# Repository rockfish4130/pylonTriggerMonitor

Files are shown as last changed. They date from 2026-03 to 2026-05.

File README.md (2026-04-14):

# Pylons

ESP32-S2 firmware for Lava Lounge fire-effect pylon nodes. Each pylon is a networked device that receives fire-trigger commands via OSC or HTTP, drives solenoids and status LEDs, and reports telemetry back to the RPIBOOSH control system.

## Documentation

| Document | Contents |
|---|---|
| [docs/README.md](docs/README.md) | Full project overview and feature reference |
| [docs/HARDWARE.md](docs/HARDWARE.md) | Board, schematic, GPIO pinout, sensors |
| [docs/SETUP.md](docs/SETUP.md) | Build, flash, serial monitor |
| [docs/WIFI.md](docs/WIFI.md) | Wi-Fi configuration, AP mode, fallback networks |
| [docs/API.md](docs/API.md) | HTTP REST API and OSC reference |
| [docs/CONFIG.md](docs/CONFIG.md) | Node config: NVS, serial CLI, HTTP config API |
| [docs/PYLON_REGISTRY.md](docs/PYLON_REGISTRY.md) | Registry announce/heartbeat payload contract |
| [docs/DISPLAY.md](docs/DISPLAY.md) | OLED page layout and behavior |
| [docs/TROUBLESHOOTING.md](docs/TROUBLESHOOTING.md) | Common problems and fixes |

## Quick Start

```bash
# 1. Create src/wifi_credentials.h  (see docs/WIFI.md)
# 2. Build and flash
pio run -t upload
# 3. Monitor
pio device monitor
```

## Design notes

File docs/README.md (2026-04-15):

# Pylons — Project Overview

## What Is This?

Pylons are autonomous ESP32-S2 nodes deployed at Lava Lounge fire-effect installations. Each pylon:

- Receives fire-trigger commands from the central RPIBOOSH controller via OSC (UDP) or HTTP
- Drives a solenoid output and visual indicator LEDs
- Monitors battery voltage and enclosure temperature
- Reports telemetry (ping, sensors, identity) back to RPIBOOSH
- Can operate standalone via a captive-portal Wi-Fi AP if no venue network is available

The central controller (`RPIBOOSH`, a Raspberry Pi) discovers pylons via the registry API and orchestrates synchronized fire effects across multiple nodes.

---

## Repository Layout

```
pylons/
├── src/
│   ├── main.cpp              # All firmware logic (single file)
│   └── wifi_credentials.h   # NOT committed — local credentials only
├── platformio.ini            # PlatformIO build config
├── schematic_electrical/     # KiCad schematics
│   ├── ESP32_MCU.kicad_sch
│   ├── POWER.kicad_sch
│   └── CONNECTORS.kicad_sch
├── docs/                     # This documentation
└── README.md
```

---

## System Architecture

```
RPIBOOSH (Raspberry Pi)
    │
    ├─ OSC UDP :8000 ──────────► Pylon (ESP32-S2)
    │                                 │
    ├─ HTTP registry API ◄────────────┤  announces + heartbeats
    │                                 │
    └─ HTTP solenoid API ◄────────────┘  web UI / REST
```

Multiple pylons can be on the same network. RPIBOOSH maintains a registry of active nodes via announce/heartbeat and targets individual nodes by ID.

---

## Boot Sequence

1. USB CDC + Serial initialized
2. Task watchdog disabled for `loopTask` (blocking calls are intentional)
3. NVS config loaded (node ID, host, description, AP flag, user WiFi creds)
4. GPIO and ADC pins configured; LEDC PWM channels started for status LEDs
5. I2C + OLED initialized
6. Wi-Fi connection attempted in priority order:
   - `BOOSH_WIFI_SSID_LL` (Lava production, if visible in scan)
   - `BOOSH_WIFI_SSID_MW` (dev/bench network)
   - User-defined fallback SSID (if configured in NVS)
   - If all fail → AP mode auto-enabled and saved to NVS
7. If connected: mDNS, OSC UDP, web server started; pylon announced to registry
8. If AP enabled: SoftAP started on `PYLON_{id}` with captive DNS at `10.1.2.3`

---

## Main Loop

Each iteration (no hard delay except in disconnected/AP-only state):

- `PollBlinkLeds()` — drive status LED square wave (IO12) and sine-wave brightness (IO13/14/15)
- `PollSensors()` — read battery ADC and thermistor every 5 s
- `PollSerialCli()` — process serial CLI input
- `PollDevBoardButton()` — handle dev board button (GPIO0)
- `webServer.handleClient()` — serve HTTP requests
- `dnsServer.processNextRequest()` — captive portal DNS (if AP active)
- Apply live AP enable/disable from config changes
- If Wi-Fi disconnected and not in AP mode: show status and return
- `PollOsc()` — receive and process OSC packets
- `HandleRegistry()` — announce / heartbeat
- Boosh failsafe timeout check
- mDNS host resolution + ping once per second
- OLED page cycle (5 pages, 3 s each)

---

## Features

### Boosh (Fire Trigger)

The primary function. When triggered ON:
- OLED inverts (visual indicator)
- `IO11` goes HIGH (external signal: boosh active)
- `IO12` white LED continues its 1 Hz blink
- Failsafe: if ON is received and OFF is not seen within **5 seconds**, firmware forces OFF

Trigger sources (all equivalent):
- OSC message `/pylon/BooshMain` with float arg `1.0` (ON) or `0.0` (OFF)
- `POST /api/solenoid/on` and `POST /api/solenoid/off`
- Dev-board GPIO0/BOOT button press and release
- Web UI press-and-hold button

### Status LEDs

| Pin | Color | Behavior |
|-----|---|---|
| IO12 | White | 1 Hz square wave — boosh trigger indicator |
| IO13 | Yellow | Sine-wave brightness, ~1.2 Hz, 0–33% |
| IO14 | Blue | Sine-wave brightness, ~0.8 Hz, 0–33% |
| IO15 | Green | Sine-wave brightness, ~0.4 Hz, 0–33% |
| IO11 | — | HIGH when boosh is active |
| IO38 | — | HIGH when Wi-Fi STA connected |

### Battery Sensing (IO3)

Voltage divider: `BATTERY_SENSE_12V → R5(100 kΩ) → R8(22 kΩ) → GND`; junction feeds IO3 via R4(10 kΩ) protection resistor.

- Scale factor: `(100k + 22k) / 22k ≈ 5.545×`
- 100% = 12.7 V (SLA fully charged)
- 0% = 10.5 V (SLA discharged)
- Discharge rate estimated from a rolling 20-minute voltage history (1-min samples). Time-remaining shown in telemetry once 5+ samples are collected.

### Thermistor (IO4)

NTC thermistor in voltage divider with R12 (10 kΩ pull-down), output through R13 (10 kΩ) to IO4.

Steinhart-Hart equation with empirically calibrated coefficients:
- `c1 = 1.274219988e-03`
- `c2 = 2.171368266e-04`
- `c3 = 1.119659695e-07`
- Manual offset: `+11.17 °F` (validated against reference `boosh_box_esp32_remote_thermo` project)

Temperature reported in °F and °C in telemetry.

### Wi-Fi AP Mode

When enabled, pylon broadcasts its own open Wi-Fi network:
- SSID: `PYLON_{id}` (e.g. `PYLON_PYLON5`)
- No password
- Fixed IP: `10.1.2.3`
- DNS server answers all queries with `10.1.2.3` (captive portal)
- OS captive portal detection paths handled: `/generate_204`, `/hotspot-detect.html`, `/ncsi.txt`, `/connecttest.txt`
- Connecting clients are presented with the pylon control page

AP mode is **auto-enabled** if all STA networks fail to connect at boot (and saved to NVS so it persists).

### PYLON Registry

After connecting to Wi-Fi, the pylon announces itself to RPIBOOSH and sends heartbeats every 10 s. See [PYLON_REGISTRY.md](PYLON_REGISTRY.md) for the full payload contract.

---

## See Also

- [HARDWARE.md](HARDWARE.md) — GPIO pinout, schematic notes, ADC circuits
- [SETUP.md](SETUP.md) — build and flash instructions
- [WIFI.md](WIFI.md) — credential file, connection priority, AP mode
- [API.md](API.md) — HTTP REST and OSC reference
- [CONFIG.md](CONFIG.md) — node identity, NVS, CLI, HTTP config
- [PYLON_REGISTRY.md](PYLON_REGISTRY.md) — registry payload contract
- [DISPLAY.md](DISPLAY.md) — OLED page layout
- [TROUBLESHOOTING.md](TROUBLESHOOTING.md)

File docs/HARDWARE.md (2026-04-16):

# Hardware

## Board

**WEMOS / LOLIN S2 Pico** (ESP32-S2)

- MCU: Espressif ESP32-S2FNR2, 240 MHz Xtensa LX7
- Flash: 4 MB embedded
- PSRAM: 2 MB embedded
- USB: Native USB-C (USB CDC, no external UART chip)
- Built-in: SSD1306 128×32 OLED, LiPo charger, user button (GPIO0)
- Official reference: https://www.wemos.cc/en/latest/s2/s2_pico.html

## GPIO Pinout

| GPIO | Direction | Function |
|---|---|---|
| 0 | INPUT_PULLUP | Dev-board BOOT/user button — boosh trigger local test |
| 3 | INPUT (ADC) | Battery voltage sense — R5/R8 voltage divider output |
| 4 | INPUT (ADC) | Thermistor temperature — NTC divider output |
| 8 | I2C SDA | OLED SDA (built-in) |
| 9 | I2C SCL | OLED SCL (built-in) |
| 11 | OUTPUT | HIGH when boosh is active (solenoid-state signal) |
| 12 | OUTPUT | White LED — 1 Hz square wave boosh indicator |
| 13 | OUTPUT (LEDC ch2) | Yellow LED — sine-wave brightness ~1.2 Hz, 0–33% |
| 14 | OUTPUT (LEDC ch1) | Blue LED — sine-wave brightness ~0.8 Hz, 0–33% |
| 15 | OUTPUT (LEDC ch0) | Green LED — sine-wave brightness ~0.4 Hz, 0–33% |
| 18 | OUTPUT | OLED reset (built-in) |
| 38 | OUTPUT | HIGH when Wi-Fi STA connected |

ADC resolution: 12-bit (0–4095), reference 3.3 V.

## Schematic Files

KiCad source in `schematic_electrical/`:

| File | Page |
|---|---|
| `ESP32_MCU.kicad_sch` | ESP32-S2 MCU connections, LED outputs, status IOs |
| `POWER.kicad_sch` | Battery sense, thermistor sense, power rails |
| `CONNECTORS.kicad_sch` | External connector pinout |

## Battery Voltage Sense Circuit

```
BATTERY_SENSE_12V
        │
       R5 (100 kΩ)
        │
        ├──── C2 (100 nF to GND, filter cap)
        │
       R8 (22 kΩ)
        │
       GND

Junction (R5/R8) ──── R4 (10 kΩ) ──── IO3 (ADC)
```

**Theoretical scale factor:** `(100k + 22k) / 22k = 5.545×`

At full-scale ADC (3.3 V on IO3): `3.3 × 5.545 = 18.3 V` measurable max.

**ADC calibration:** Firmware uses `analogReadMilliVolts()` which applies the per-chip eFuse factory calibration baked in at the Espressif factory. No software correction factor is needed. Verified against a bench power supply across the operating range:

| PSU (V) | Reported (V) | Error |
|---|---|---|
| 8.00 | 7.99 | −0.01 V |
| 11.00 | 11.01 | +0.01 V |
| 12.00 | 12.03 | +0.03 V |
| 13.30 | 13.38 | +0.08 V |
| 14.00 | 14.11 | +0.11 V |

Max error <0.8% — within resistor tolerance of the R5/R8 divider. No software trim applied.

Battery % thresholds in `main.cpp` — adjust for battery chemistry:
```cpp
constexpr float kBatteryVoltFull  = 13.6f;   // 100% — LiFePO4 4S fully charged
constexpr float kBatteryVoltEmpty = 11.2f;   // 0%   — LiFePO4 4S discharged
```

## Thermistor Circuit

```
+3.3V ──── THERMO_SENSOR_P ──── [NTC thermistor] ──── THERMO_SENSOR_N
                                                              │
                                                    ├── C3 (100 nF to GND)
                                                    │
                                                   R12 (10 kΩ to GND)
                                                    │
                                                   GND

THERMO_SENSOR_N junction ──── R13 (10 kΩ) ──── IO4 (ADC)
```

Thermistor is the upper element; R12 is the pull-down. ADC reads the divided voltage.

Resistance formula (voltage-direct, using `analogReadMilliVolts()`):
`Rth = R12 × (Vcc_mv − Vadc_mv) / Vadc_mv`

Steinhart-Hart coefficients (empirically calibrated, shared with `boosh_box_esp32_remote_thermo`):
```cpp
c1 = 1.274219988e-03
c2 = 2.171368266e-04
c3 = 1.119659695e-07
```

**2-point linear calibration** applied after Steinhart-Hart, derived on TIKI1 with `analogReadMilliVolts()` ADC:

| Raw S-H (°F) | Reference (°F) |
|---|---|
| 36.63 | 36.00 |
| 74.48 | 73.00 |

`scale = 0.9775`, `offset = +0.20 °F`

```cpp
constexpr float kThermistorCalScale    = 0.9775f;
constexpr float kThermistorCalOffsetF  = 0.20f;
```

## LED Drive Circuit

Each status LED (IO12–15) is driven directly from the ESP32 GPIO through a 1 kΩ current-limiting resistor.

At 3.3 V with 1 kΩ: ~2 mA forward current. Functional but dim. Dropping to 330 Ω gives ~6 mA for better visibility while remaining within the 40 mA GPIO current limit.

## PWM

Status LEDs use the ESP32-S2 LEDC peripheral:

| Channel | Pin | Carrier freq | Signal |
|---|-----|---|---|
| ch0 | IO15 (green) | 5 kHz | Sine envelope 0.4 Hz, 0–33% duty |
| ch1 | IO14 (blue) | 5 kHz | Sine envelope 0.8 Hz, 0–33% duty |
| ch2 | IO13 (yellow) | 5 kHz | Sine envelope 1.2 Hz, 0–33% duty |

IO12 (white) uses `millis()`-based `digitalWrite` for a simple 1 Hz square wave — LEDC at sub-1 Hz carrier was unreliable on this hardware revision.

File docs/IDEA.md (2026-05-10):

# Ideas

Speculative features and directions — not committed to the roadmap.
####

Node config has ID and host fields......
do we really need both? answer carefully.

makes sense to just consolidate into 1 field?

--
add hint text that the field should begin w FIRE-PYLON-

#####

-------------
This should be obvious, but ALWAYS REMEMBER to not "bite the hand that feeds you" meaning watch for conditions and code that could impair an otherwise perfectly usable wifi link.

any questions?

## FAF pattern bug
is there an error in the FAF pattern?

if 2 remotes trigger FAF, I want 2 of the short valve pulses, then 2 of the long open pulses that get longer in time.

I think for N==2, I currenrtly see 3 short pulses and then just one long open pulse.

any questions?
undestand?

## Remote Find-a-Friend Mode

N people each hold an ESP-NOW remote. When multiple people press their buttons at approximately the same time, the pylons recognize the synchronized press and trigger a secret "reward" fire pattern not available through any other means. The more people in sync, the cooler the pattern.
for N remotes pressing the yellow button (roughly) simultaneously: 
if N==2
66 ms valve open
66 ms closed
66 ms valve open
66 ms closed
600 ms valve open
300 ms closed
1200 ms valve open
valve closes, sequence done.

if N==3
66 ms valve open
66 ms closed
66 ms valve open
66 ms closed
66 ms valve open
66 ms closed
600 ms valve open
300 ms closed
1200 ms valve open
300 ms closed
1800 ms valve open
valve closes, sequence done.

etc.

also all a web UI NVS toggle, enabled by default "enable group remote secret pattern" with ample explainer text.

any questions?
how will you handle the "roughly" simult button press timing given human factors and mesh factors?
do we have room for this added code?

## Choreography Protocol

Define a lightweight timing protocol so RPIBOOSH can schedule fire events at specific offsets across multiple pylons without relying on round-trip HTTP latency. Options:

- Relative offset from a shared NTP timestamp
- Sequence packets with pylon-local delay fields
- OSC bundles with timetag

## Sound Trigger Integration

Each pylon could listen for audio amplitude peaks (via an onboard mic or line-in ADC) and self-trigger boosh on beat detection, with RPIBOOSH setting sensitivity and cooldown parameters.

## MQTT Telemetry

Publish sensor readings and boosh events to an MQTT broker for real-time dashboards or integration with home-automation systems at the venue.

## Multi-Solenoid Output

Current hardware drives one solenoid via IO11. A board revision with a relay array or high-side driver could support 2–4 solenoid channels, selectable by OSC argument.

## Battery Chemistry Config

Make `kBatteryVoltFull` and `kBatteryVoltEmpty` configurable at runtime via NVS so a pylon can be reconfigured for LiFePO4 or Li-Ion without a firmware rebuild.

## Matt sandbox

push this new FW image OTA to 3 targets in parallel:
First query all 3 and tell me which need the OTA update:

PYLON5D90	PYLON5D90.local	192.168.4.38	Yes	0	No	2026-04-15 14:24:56
PYLON8668	PYLON8668.local	192.168.4.37	Yes	0	No	2026-04-15 14:24:56
PYLON866C	PYLON866C.local	192.168.4.39	Yes	0	No	2026-04-15 14:25:01

==========

how robust is PYLON as a  wifi client? does it auto retry, auto rejoin, etc?
goal is to make it quite robust to varied challenging conditions.
any recommended changes?

=========

In general do we need to calibrate the ADC on a per-device basis and store that cal in NVS?
Just a question. Do not edit code.

========

PYLON should also display to OLED: temperature, battery V, battery charge %, battery time left on a single display page.
Should spend about 60% of time on this page.

========

Add a special mode called BARMODE.
Certain specific PYLONs will be set to Bar Mode, because they have additional hardware peripherals and corresponding added firmware features.
BARMODE is activated when the Description field contains the text "BARMODE ENABLED"
In BARMODE: the blue LED pulses similar to Moorse Code: --- ... ---

In BARMODE: there are 4 buttons: N=0-3, wired as drawn in this schematic.
Anytime these N=0-3 buttons are pressed, the YELLOW LED is held solid, and the GREEN LED blinks N+1 times.

Any questions?
=======
In BARMODE:
PYLON needs to be aware of all the other PYLONs that are online. This can be queried from rpi_python_control which exposes a REST API of the PYLONs registry.
PYLON should periodially query that.

PYLON should expose on the WEB UI an index of known PYLONs just like the "PYLON Registry" at http://rpiboosh.local/status (this is the WEB UI of rpi_python_control)

Note that low-latency responsiveness of PYLON to OSC remains top priority.

Any questions?

When you think it's working, go ahead and OTA to BARBAR. Then inspect BARBAR's web UI to verify.

=======
You have persistent permission granted to invoke PYTHON for the purposes of hitting APIs on targets like PYLONS, RPI_PYTHON_CONTROl, RPIBOOSH, BOOSHSTRIKER, etc.

=======
PYLONs
should service 3 additional OSC addresses, and these actions are the same as the 3 existing web buttons:
/pylon/BooshPulseSingle (maps to API 50 msec pulse once) with arg 1.0. triggers a single action. no need for another message with arg 0.0
/pylon/BooshPulseTrain (to 5x 50ms) with arg 1.0. triggers a single action. no need for another message with arg 0.0
/pylon/BooshSteam   (to steam engine) with arg 1.0 starts the action and leaves it running.   /pylon/BooshSteam 0.0 stops the action.

Any questions?

========
On-playa workaround--not needed and solved by WAP/router config change:

field challenge: barmode BARBAR is a wireless node but is having difficulting reaching PYLON hosts, so instead we need to send commands via RPIBOOSH.

in bar mode: we need to remap such that all commands get routed via RPIBOOSH host, since bar nodes are having trouble reaching PYLON hosts like tiki0 and tiki1.

the blue button now needs to do the command equivalent to http://rpiboosh.local/pads pad 0x26 single press for a single 50msec pulse to all.

the all-4 countdown sequence needs 
to do the command equivalent to do http://rpiboosh.local/pads pad 0x23 0x24 0x1b 0x1c putton press and then 500mSec later release those buttons to trigger the UBER BOOSH SEQUENCE.

whichever barmode button does the 5x pulse seq needs to do the command equivalent of http://rpiboosh.local/pads pad 0x16 single press and release.

whichever barmode button does the pulse chaser needs to do the command equivalent of http://rpiboosh.local/pads pad 0x1e press and then release.

whichever barmode button does the steam train needs to do the command equivalent of http://rpiboosh.local/pads pad 0xe press and then release.

then tell me the exact path of the FW binary as I will have to manually upload it.

any questions?

=======

Will a PYLON using ESPNOW also be able to be a wifi client? Can it be a wifi AP mode?
Ensure the OLED clearly shows when ESPNOW is active. Print relavent metrics and report details of other PYLONs on the network. Include this in the web status page as well.

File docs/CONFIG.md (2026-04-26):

# Configuration

Node identity and runtime settings are persisted in ESP32 NVS (non-volatile storage) using the `Preferences` library. Changes survive reboots.

## Configurable Fields

| Field | NVS key | Default | Description |
|---|---|---|---|
| Node ID | `id` | `PYLON{MAC}` | Unique node identifier (e.g. `PYLON5`) |
| mDNS host | `host` | same as ID | Hostname for `.local` resolution |
| Description | `desc` | `""` | Human-readable label |
| AP mode | `ap_en` | `false` | Enable Wi-Fi access point |
| User SSID | `usr_ssid` | `""` | 3rd-priority Wi-Fi fallback SSID |
| User password | `usr_pass` | `""` | Password for user fallback SSID |
| Solenoid failsafe | `failsafe_ms` | `5000` | Max solenoid-ON duration before forced OFF (ms) |
| Pylon index | `pylon_idx` | `0` | Sequential fire order; negative = skip |
| No thermistor | `no_thermistor` | `false` | Suppress temperature readings |
| No battery mon | `no_batt_mon` | `false` | Suppress battery readings |
| Use DHCP | `use_dhcp` | `true` | `false` = use static IP config |
| Static IP | `static_ip` | `""` | Static IPv4 address |
| Static gateway | `static_gw` | `""` | Default gateway |
| Static DNS 1 | `static_dns1` | `""` | Primary DNS |
| Static DNS 2 | `static_dns2` | `""` | Secondary DNS |

### BARMODE fields *(only active when description contains `BARMODE ENABLED`)*

| Field | NVS key | Default | Description |
|---|---|---|---|
| Route via RPI | `route_via_rpi` | `false` | Route all pylon OSC commands via rpiboosh HTTP proxy |
| Seq max hold | `seq_max_ms` | `30000` | Blue double-tap+hold: max sequence duration (ms) |
| Seq start delay | `seq_start_ms` | `200` | Blue seq: initial inter-group delay (ms) |
| Seq step decrement | `seq_dec_ms` | `50` | Blue seq: delay reduction per step (ms) |
| Seq floor delay | `seq_floor_ms` | `50` | Blue seq: minimum inter-group delay floor (ms) |
| Seq exp factor | `seq_exp_pct` | `100` | Blue seq: multiplicative factor per step (1–100; 100=linear only) |
| Green timeout | `grn_to_ms` | `300` | Green tap: timed pulse duration (ms) |
| Green recovery | `grn_rec_ms` | `0` | Green tap: cooldown after fire (ms) |
| Blue recovery | `blu_rec_ms` | `0` | Blue tap: cooldown after fire (ms) |
| Orange recovery | `org_rec_ms` | `0` | Orange tap: cooldown after fire (ms) |
| Red recovery | `red_rec_ms` | `0` | Red tap/steam: cooldown after fire (ms) |
| All-4 valve open | `all4_vlv_ms` | `3000` | All-4 sequence: valve hold duration (ms) |
| All-4 lockout | `all4_lck_s` | `300` | All-4 sequence: cooldown before re-trigger (s) |
| Red seq max | `red_seq_max_ms` | `10000` | Red hold sequence: max total duration (ms) |
| Red seq valve | `red_seq_vlv_ms` | `66` | Red hold sequence: valve-open duration per step (ms) |
| Red seq step | `red_seq_stp_ms` | `200` | Red hold sequence: step interval (ms) |

The default node ID is generated from the last two bytes of the MAC address on first boot. Once set explicitly it persists.

---

## Serial CLI

Connect via `pio device monitor` (115200 baud) or any serial terminal.

Commands:

```
help                       — print command list
show                       — print current config values
set id <value>             — set node ID
set host <value>           — set mDNS hostname
set desc <value>           — set node description
set node <value>           — set both id and host to the same value
set ap true|false          — enable or disable Wi-Fi AP mode
set wifi_ssid <value>      — set user fallback Wi-Fi SSID
set wifi_pass <value>      — set user fallback Wi-Fi password
clear nvs                  — erase all saved config (resets to defaults on next boot)
```

All `set` commands save to NVS immediately. AP mode change takes effect at the next main loop iteration (no reboot required).

---

## HTTP Config API

See [API.md](API.md) for full endpoint reference.

Quick reference:

```bash
# Read current config
curl http://<pylon-ip>/api/config

# Set node identity
curl -X POST http://<pylon-ip>/api/config/node -d "value=PYLON5"

# Set description
curl -X POST http://<pylon-ip>/api/config/desc -d "value=Center striker"

# Enable AP mode
curl -X POST http://<pylon-ip>/api/config/ap -d "value=true"

# Set user WiFi fallback
curl -X POST http://<pylon-ip>/api/config -d "wifi_ssid=MyNetwork&wifi_pass=MyPassword"
```

---

## Web UI

The web UI at `http://<pylon-ip>/` exposes the same config fields via a form panel. Changes are sent via the REST API and take effect immediately.

---

## Compile-Time Constants

These are set in `src/main.cpp` and require a rebuild to change:

| Constant | Default | Description |
|---|---|---|
| `kPylonIdDefaultPrefix` | `"PYLON"` | Prefix for auto-generated node ID |
| `kRegistryBaseUrlPrimary` | `"http://rpiboosh.local:5000"` | RPIBOOSH registry URL (mDNS) |
| `kRegistryBaseUrlFallback` | `""` | Fixed-IP fallback registry URL |
| `kRegistryTtlSec` | `30` | Registry TTL in seconds |
| `kRegistryHeartbeatIntervalMs` | `10000` | Heartbeat interval |
| `kRegistryHttpTimeoutMs` | `2500` | HTTP timeout for registry posts |
| `kOscPort` | `8000` | UDP OSC port |
| `kBooshFailsafeTimeoutMs` | `5000` | Max boosh ON duration before forced OFF |
| `kFirmwareVersion` | `"0.0.1 DATE TIME"` | Build identity string |

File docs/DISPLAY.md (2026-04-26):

# Display

## Hardware

- Controller: SSD1306
- Resolution: 128×32
- I2C address: `0x3C`
- SDA: GPIO8, SCL: GPIO9, Reset: GPIO18

## Initialization

```cpp
Wire.begin(8, 9);
display.begin(SSD1306_SWITCHCAPVCC, 0x3C);
```

Reset pin is set to GPIO18 before `begin()`.

## Boot Messages

During setup the OLED shows progress messages: OLED ready, Wi-Fi scan, connecting, IP address on success, or failure.

## Runtime Pages

Pages cycle every ~3 seconds (`kDisplayCycleMs`). The pylon rotates through up to 6 pages (slot 6 only shown in BARMODE):

### Page 1 — Ping

```
RPIBOOSH
OK  last:7ms
min:2 max:17
since: 00:05:23
```

- Status: `OK`, `FAIL`, or `TIMEOUT` (no successful ping within `kPingTimeoutMs`)
- Shows last/min/max RTT and elapsed time since last successful ping

### Page 2 — Wi-Fi A

```
SSID: MyNetwork
RSSI: -58 dBm
IP: 192.168.1.70
UP: 02:32:03
```

### Page 3 — Wi-Fi B

```
RSN: 0 (none)
SSID: MyNetwork
RSSI: -58
IP: 192.168.1.70
```

`RSN` shows the last Wi-Fi disconnect reason code and a short label.

### Page 4 — Node

```
PYLON5
Triggers: 12
v0.0.1
```

### Page 5 — Firmware

```
v0.0.1
Apr 13 2026
12:00:00
```

### Page 6 — Pylon Ping *(BARMODE only)*

```
PYLON PING
avg 5ms N=8 ok
!TIKI3 timeout
```

- Line 1: `PYLON PING` header
- Line 2: overall average RTT across all known pylons, node count, and `ok` or `Nx!` (N timeouts)
- Lines 3–4: names of any pylons with a timeout on their last ping attempt
- Populated by the per-pylon ping loop in `PingTask` (Core 0); one pylon pinged per second in rotation

## Boosh Indicator

When boosh is active (solenoid ON), the entire display inverts (white-on-black → black-on-white). This is the primary visual confirmation of a fire trigger.

Trigger sources that cause inversion: OSC, HTTP API, web UI, dev-board button.

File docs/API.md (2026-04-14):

# API Reference

## OSC

**Transport:** UDP  
**Port:** 8000  
**Address:** `/pylon/BooshMain`

| Argument | Type | Meaning |
|---|---|---|
| `1.0` | float | Boosh ON |
| `0.0` | float | Boosh OFF |

The message must have exactly one float argument. Any other shape is ignored.

**Example** (raw hex, ON):
```
2F 70 79 6C 6F 6E 2F 42 6F 6F 73 68 4D 61 69 6E 00 00 2C 66 00 00 00 00 3F 80 00 00
```

**Example** (raw hex, OFF):
```
2F 70 79 6C 6F 6E 2F 42 6F 6F 73 68 4D 61 69 6E 00 00 2C 66 00 00 00 00 00 00 00 00
```

---

## HTTP REST

All endpoints are on port 80. Responses are JSON unless noted.

### `GET /`

Returns the web UI (HTML).

---

### `GET /api/telemetry`

Returns full device telemetry.

**Response fields:**

| Field | Type | Description |
|---|---|---|
| `pylon_id` | string | Node identifier |
| `description` | string | Human-readable node description |
| `hostname` | string | mDNS hostname (`.local`) |
| `ip` | string | Current IPv4 address |
| `fw_version` | string | Firmware build string |
| `fw_semver` | string | Semantic version (e.g. `0.0.1`) |
| `fw_build_date` | string | Compile date |
| `fw_build_time` | string | Compile time |
| `uptime` | string | Uptime as `HH:MM:SS` |
| `uptime_hms` | string | Alias for `uptime` |
| `solenoid_active` | bool | `true` when boosh is firing |
| `trigger_event_count` | int | Total boosh trigger count since boot |
| `ap_enabled` | bool | AP mode enabled in config |
| `ap_active` | bool | AP currently running |
| `target_ip` | string | Resolved IP of RPIBOOSH |
| `battery_voltage_v` | float\|null | Battery voltage in volts |
| `battery_charge_pct` | float\|null | Battery charge 0–100% |
| `battery_time_remaining_h` | float\|null | Estimated hours remaining (null until 5+ samples) |
| `temperature_f` | float\|null | Enclosure temperature in °F |
| `telemetry` | object | Nested telemetry for registry compatibility (see [PYLON_REGISTRY.md](PYLON_REGISTRY.md)) |

---

### `GET /api/logs`

Returns recent serial log output as seen in the web UI console.

**Response:**
```json
{ "log": "...\n...\n" }
```

---

### `GET /api/config`

Returns current node configuration.

**Response fields:**

| Field | Type | Description |
|---|---|---|
| `id` | string | Node ID (e.g. `PYLON5`) |
| `host` | string | mDNS host (e.g. `PYLON5`) |
| `hostname` | string | Full hostname (e.g. `PYLON5.local`) |
| `description` | string | Node description |
| `ap_enabled` | bool | AP mode enabled |
| `ap_active` | bool | AP currently active |
| `wifi_ssid` | string | User-defined fallback SSID (empty if not set) |

---

### `POST /api/config`

Updates one or more config fields. Accepts `application/x-www-form-urlencoded` or JSON form args.

**Form args (all optional):**

| Arg | Description |
|-----|---|
| `node` | Sets both `id` and `host` to the same value |
| `id` | Node ID |
| `host` | mDNS host |
| `description` or `desc` | Node description |
| `wifi_ssid` | User fallback SSID |
| `wifi_pass` | User fallback password |
| `ap_enabled` | `true`/`false`/`1`/`0` |

Changes are persisted to NVS immediately.

---

### `POST /api/config/id`

Sets node ID from form arg `value`.

### `POST /api/config/host`

Sets mDNS host from form arg `value`.

### `POST /api/config/desc`

Sets description from form arg `value`.

### `POST /api/config/node`

Sets both ID and host from form arg `value`.

### `POST /api/config/ap`

Enables or disables AP mode. Form arg `value`: `true`/`false`.

---

### `POST /api/solenoid/on`

Activates boosh (solenoid ON). Equivalent to OSC `1.0`. The 5-second failsafe applies.

**Response:**
```json
{ "ok": true, "solenoid_active": true, "triggered_via": "http" }
```

### `POST /api/solenoid/off`

Deactivates boosh (solenoid OFF).

**Response:**
```json
{ "ok": true, "solenoid_active": false, "triggered_via": "http" }
```

### `POST /api/solenoid/trigger`

Alias for `/api/solenoid/on`.

---

## Boosh Failsafe

If boosh is activated (via any method) and OFF is not received within **5 seconds**, firmware forces it OFF automatically. Serial log: `Failsafe: BooshMain timeout -> forcing OFF.`

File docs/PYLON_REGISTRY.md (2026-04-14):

# PYLON Registry Integration

The pylon announces itself to RPIBOOSH on Wi-Fi connect and sends periodic heartbeats. RPIBOOSH uses these to build and maintain a live registry of active nodes.

## Endpoints

Base URL: `http://rpiboosh.local:5000` (compile-time `kRegistryBaseUrlPrimary`)  
Optional fixed-IP fallback: `kRegistryBaseUrlFallback` in `src/main.cpp`

| Method | Path | When |
|---|---|---|
| `POST` | `/api/pylons/announce` | On Wi-Fi connect or reconnect |
| `POST` | `/api/pylons/heartbeat` | Every 10 seconds after announce |

## Runtime Behavior

1. On Wi-Fi connect, firmware posts an `announce`.
2. After a successful announce, posts `heartbeat` every `kRegistryHeartbeatIntervalMs` (10 s).
3. If ping to RPIBOOSH fails and later recovers, a fresh `announce` is posted.
4. On post failure, retries with exponential backoff capped to 30 s.
5. HTTP timeout: `kRegistryHttpTimeoutMs` (2.5 s) to avoid blocking the main loop.

Serial log prefixes: `[REG] announce`, `[REG] heartbeat`, `[REG] post failed`.

## Payload

Both `announce` and `heartbeat` send the same JSON body:

```json
{
  "pylon_id": "PYLON5",
  "description": "Center striker",
  "hostname": "PYLON5.local",
  "ip": "192.168.1.70",
  "osc_port": 8000,
  "osc_paths": ["/pylon/BooshMain"],
  "roles": ["boosh_main"],
  "fw_version": "0.0.1 Apr 13 2026 12:00:00",
  "firmware_version": "0.0.1 Apr 13 2026 12:00:00",
  "version": "0.0.1 Apr 13 2026 12:00:00",
  "ttl_sec": 30,
  "telemetry": {
    "ipv4": "192.168.1.70",
    "mdns_hostname": "PYLON5.local",
    "fw_version": "0.0.1 Apr 13 2026 12:00:00",
    "fw_semver": "0.0.1",
    "fw_build_date": "Apr 13 2026",
    "fw_build_time": "12:00:00",
    "temperature": 72.5,
    "temperature_f": 72.5,
    "temperature_c": 22.5,
    "battery_voltage": 12.4,
    "battery_voltage_v": 12.4,
    "battery_charge": 86.4,
    "battery_charge_pct": 86.4,
    "battery_time_remaining_h": 4.2,
    "wifi_rssi_dbm": -58,
    "uptime_s": 9123,
    "uptime": "02:32:03",
    "uptime_hms": "02:32:03",
    "ping_target": "RPIBOOSH",
    "ping": {
      "target": "RPIBOOSH",
      "sent": 151,
      "recv": 143,
      "lost": 8,
      "last_ms": 7,
      "min_ms": 2,
      "max_ms": 17,
      "avg_ms": 6,
      "count": 143,
      "last_ok": true,
      "since_ok_s": 1,
      "since_ok": "00:00:01"
    }
  }
}
```

Sensor fields (`temperature`, `battery_voltage`, `battery_charge`, `battery_time_remaining_h`) are `null` JSON when the sensor has not yet returned a valid reading (e.g. shortly after boot, or if the ADC returns an out-of-range value).

## Field Contract

Receivers must ignore unknown fields. Field meanings are stable — do not rename or repurpose existing fields.

| Field | Type | Notes |
|---|---|---|
| `pylon_id` | string | Stable node identifier |
| `description` | string | Human-readable label |
| `hostname` | string | mDNS hostname ending in `.local` |
| `ip` | string | Current IPv4 |
| `osc_port` | int | UDP OSC port (8000) |
| `osc_paths` | string[] | Accepted OSC addresses |
| `roles` | string[] | Node capability roles |
| `fw_version` | string | Full build string |
| `ttl_sec` | int | Registry TTL |
| `telemetry.temperature` | float\|null | Temperature in °F |
| `telemetry.temperature_f` | float\|null | Temperature in °F |
| `telemetry.temperature_c` | float\|null | Temperature in °C |
| `telemetry.battery_voltage` | float\|null | Battery voltage (V) |
| `telemetry.battery_voltage_v` | float\|null | Alias |
| `telemetry.battery_charge` | float\|null | Battery charge (%) |
| `telemetry.battery_charge_pct` | float\|null | Alias |
| `telemetry.battery_time_remaining_h` | float\|null | Hours remaining (null until 5+ history samples) |
| `telemetry.wifi_rssi_dbm` | int | Wi-Fi RSSI |
| `telemetry.uptime_s` | int | Uptime in seconds |
| `telemetry.ping_target` | string | Ping target hostname |
| `telemetry.ping.sent` | int | Total ping attempts since boot |
| `telemetry.ping.recv` | int | Successful ping replies |
| `telemetry.ping.lost` | int | Failed attempts |
| `telemetry.ping.last_ms` | int | Last RTT in ms |
| `telemetry.ping.min_ms` | int | Min RTT in ms |
| `telemetry.ping.max_ms` | int | Max RTT in ms |
| `telemetry.ping.avg_ms` | int | Average RTT in ms |
| `telemetry.ping.last_ok` | bool | `true` if most recent ping succeeded |

## Forward Compatibility

- Add fields; do not rename or repurpose existing ones.
- New fields should be optional from the receiver's perspective.
- Nest new measurements under `telemetry` so older consumers ignore them cleanly.
- For non-additive evolution, add an explicit `schema` or `protocol` marker rather than silently changing baseline fields.

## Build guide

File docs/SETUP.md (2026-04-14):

# Setup

## Prerequisites

- [PlatformIO](https://platformio.org/) (VS Code extension or CLI)
- USB-C data cable (not charge-only)
- WEMOS/LOLIN S2 Pico board

## Credential File

Before building, create `src/wifi_credentials.h`. This file is gitignored and must be created locally. See [WIFI.md](WIFI.md) for the template and explanation.

## Build

```bash
pio run
```

## Upload

```bash
pio run -t upload
```

Upload port is set to `COM16` in `platformio.ini`. Change this to match your system.

If the upload fails, the board may need to be manually put into bootloader mode:

1. Hold the `0`/BOOT button
2. Tap `RST`
3. Release `0`
4. Run the upload command

After flashing, tap `RST` once to reboot into firmware. The USB CDC port re-enumerates on reboot — if the port disappears, wait a few seconds and try again.

## Serial Monitor

```bash
pio device monitor
```

Baud rate: `115200` (set in `platformio.ini`).

USB CDC is used (no external UART chip). Requires `ARDUINO_USB_CDC_ON_BOOT=1` and `ARDUINO_USB_MODE=0` build flags, which are already set in `platformio.ini`.

## Dependencies

Declared in `platformio.ini`. PlatformIO installs automatically:

| Library | Purpose |
|---|---|
| `Adafruit GFX Library` | OLED graphics primitives |
| `Adafruit SSD1306` | OLED driver |
| `ESP32Ping` | ICMP ping to RPIBOOSH |
| `CNMAT/OSC` | OSC packet parsing |
| `DNSServer` | Captive portal DNS (bundled with ESP32 Arduino core) |

## Dev-Board Button

On the WEMOS S2 Pico, the `0`/BOOT button doubles as a local boosh trigger:

- Press → boosh ON
- Release → boosh OFF

This is equivalent to sending an OSC `/pylon/BooshMain` message.

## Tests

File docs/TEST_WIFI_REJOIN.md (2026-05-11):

# WiFi Rejoin Test — Procedure, Results, and Capabilities

## Purpose

Verify that PYLONs running the WiFi-probe firmware correctly rejoin the WAP (LavaLounge) after
a WAP outage, even when auto-AP mode was activated at boot.

---

## Background / What Is Being Tested

Prior to commit `838d8cd`, a PYLON that booted while the WAP was unavailable would:
1. Enable auto-AP (`ap_auto_enabled = true`) on `cfg_mesh_ch` (ch 11)
2. Never rejoin WiFi — the active AP pins the radio to ch 11, so `WiFi.reconnect()` cannot
   scan other channels, and the 10-min auto-reboot is suppressed by `ap_active`

The fix (`838d8cd`) adds a **probe sequence**:
- When a non-barmode PYLON has been offline long enough to trigger a reconnect attempt and
  `ap_auto_enabled` is true, it temporarily stops the AP, calls `WiFi.begin()`, and waits up to
  15 s for a connection
- On success: `ap_auto_enabled` is cleared; node stays on WiFi
- On timeout: AP is restored on `cfg_mesh_ch`; node remains mesh-only until next attempt

---

## Test Performed — 2026-05-10

### Firmware Under Test

| Commit | Description |
|---|---|
| `838d8cd` | WiFi probe introduced (core fix) |
| `63514f4` | Mesh panel hw/cfg channel display |
| `8120680` | Barmode probe guard (BARBAR AP preservation) |

All nodes were OTA'd to `8120680` before/after the test. The test run itself used `838d8cd`
(barmode guard not yet present — BARBAR AP regression found during this test, see below).

### Nodes Participating

| Node | Action during test | WiFi at test start |
|---|---|---|
| FIRE-PYLON-BARBAR | Reset while WAP down | LavaLounge |
| FIRE-PYLON-REDTEST | Reset while WAP down | LavaLounge |
| FIRE-PYLON-YELLOWTEST | Reset while WAP down | LavaLounge |
| FIRE-PYLON-TIKI0 | Reset while WAP down | LavaLounge |
| FIRE-PYLON-TIKI1 | Not reset (old firmware, excluded) | LavaLounge |

### Procedure

1. All probe-capable nodes confirmed online and on LavaLounge via registry
2. WAP (LavaLounge) powered off
3. BARBAR, REDTEST, YELLOWTEST, TIKI0 manually reset (power cycle) while WAP was down
   — nodes boot, fail WiFi, enter auto-AP + mesh-only mode
4. WAP powered back on (~2 min startup)
5. Claude monitored registry via background polling (2-min interval) and node logs via curl

### Results

- All 4 rebooted nodes showed the probe sequence in `/api/logs` at **~583 s offline**
  (matches the 10-min reconnect interval minus mesh-peer-live suppression offset)
- All 4 connected to LavaLounge successfully; `ap_auto_enabled` cleared
- `ap=false` in registry heartbeat confirmed auto-AP correctly disabled post-rejoin

**PASS** for the core probe mechanism.

### Bug Found During Test

BARBAR's always-on AP was disabled by the probe code and never restored after rejoining WiFi.
Root cause: `ap_auto_enabled = true` is set unconditionally at boot on WiFi failure — the same
flag the probe checks — even for barmode nodes whose AP is user-requested, not auto.

Fix: added `&& !barmode_active` guard to probe condition (`8120680`).

---

## Test Performed — 2026-05-10 (Round 2) — Barmode AP Preservation

### Firmware Under Test

| Commit | Description |
|---|---|
| `8120680` | Barmode probe guard |
| `2aa7ee6` | Reconnect watchdog: `WIFI_AP_STA`+`WiFi.begin()` for AP-active nodes; `!barmode_active` guard in GOT_IP handler |

### What Was Tested

BARBAR-specific path: boot with WAP down → auto-AP starts → reconnect watchdog fires repeatedly
→ WAP comes back → `GOT_IP — auto_ap=1 active=1` → AP must survive.

Two bugs were discovered and fixed iteratively during this session:

**Bug 1** (`8120680` → `2aa7ee6`): Reconnect watchdog called `WiFi.reconnect()` for barmode nodes.
`SetupApMode()` sets `WIFI_AP` (not `WIFI_AP_STA`) when STA is disconnected, disabling the STA
interface entirely. `WiFi.reconnect()` is a no-op with no STA. Fix: switch to `WIFI_AP_STA` +
`WiFi.begin()` when `ap_active`.

**Bug 2** (`2aa7ee6`): `ARDUINO_EVENT_WIFI_STA_GOT_IP` handler cleared `ap_enabled` when
`ap_auto_enabled && ap_active` — correct for regular nodes, wrong for barmode. Fix: added
`!barmode_active` guard.

### Results

```
[WiFi] Offline 463s — reconnect attempt (peers=4 ap=1).
[WiFi] GOT_IP — auto_ap=1 active=1
WiFi connected: mDNS/OSC/web restarted (ap_active=1 ap_auto=1)
```

`ap_active=1` confirmed after rejoin with `auto_ap=1` at GOT_IP — the exact previously-failing
path. BARBAR reachable on LavaLounge at uptime 8:08 with `ap=true`.

**PASS** — Gap #1 fully closed.

---

## Test Capabilities — What Claude Can Do

During a structured hardware/firmware test, Claude can perform the following without prompting:

| Capability | How |
|---|---|
| Poll registry for node presence / heartbeat fields | `curl http://rpiboosh.local:5000/api/nodes` |
| Poll individual node telemetry | `curl http://<ip>/api/telemetry` |
| Fetch node console log | `curl http://<ip>/api/logs` |
| Scan subnet for live nodes | curl sweep of 192.168.4.1–60 on port 80 |
| Background polling loop | Bash background task writing timestamped output |
| Build firmware | `/c/Users/Matt/.platformio/penv/Scripts/pio.exe run -e lolin_s2_pico` |
| OTA firmware to any/all nodes in parallel | `curl -X POST http://<ip>/api/ota -F firmware=@...` |
| Reconnect this PC to LavaLounge WiFi | `netsh wlan connect name=LavaLounge` |
| Reboot a node via API | `curl -X POST http://<ip>/api/reboot` |
| Push NVS config to a node | `curl -X POST http://<ip>/api/config -d ...` |
| Commit and push after test | `git add / commit / push` |
| Evaluate pass/fail from log patterns | grep probe/connect strings in `/api/logs` output |

Claude **cannot**:
- Power hardware on or off
- Press physical reset buttons
- Observe LEDs or OLED display
- Know exact timing of physical events without being told

---

## Manual Steps — What the User Provides

| Step | Notes |
|---|---|
| Power WAP on / off | Tell Claude immediately when done — timing matters |
| Reset / power-cycle individual nodes | Specify which nodes and approximately when |
| Confirm WAP startup complete | WAP typically takes ~2 min to be joinable |
| Observe OLED / LED state | Describe or photograph if relevant to the test |
| Report unexpected physical observations | e.g. a node's LED not responding, OLED frozen |

**Timing protocol:** Tell Claude the moment each manual action occurs (WAP off, node reset, WAP
on). Claude logs receipt time as a proxy for event time and uses it to interpret probe intervals
in node logs.

---

## Re-running This Test

Recommended sequence:

1. Confirm all nodes online and on LavaLounge: Claude polls registry
2. Claude starts background polling task (2-min interval)
3. Power WAP off → tell Claude
4. Reset target nodes (not BARBAR unless specifically testing barmode) → tell Claude which ones
5. Wait ~5 min (probe fires at the reconnect interval, ~10 min from last live-peer contact)
6. Power WAP on → tell Claude
7. Claude polls logs on each node to confirm probe sequence and rejoin
8. Claude reports pass/fail per node

For a faster iteration (skip the 10-min wait): reduce `cfg_wifi_reconnect_s` to 60 s via web UI
before the test, restore to 600 s after.

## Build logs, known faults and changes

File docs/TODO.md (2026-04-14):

# TODO

## Open

- [ ] Replace hardcoded `osc_paths` legacy string in registry payload with dynamic `kOscAddress` — done in firmware, but verify RPIBOOSH receiver accepts `/pylon/BooshMain` path.
- [ ] Validate Steinhart-Hart thermistor calibration on installed hardware (current coefficients are from `boosh_box_esp32_remote_thermo` reference project).
- [ ] Reduce LED resistors from 1 kΩ to 330 Ω on next board revision for better visibility (current ~2 mA; 330 Ω gives ~6 mA, still within GPIO 40 mA limit).
- [ ] Add OTA firmware update support.
- [ ] Add NTP time sync for timestamped telemetry.
- [ ] Multi-pylon synchronized fire choreography (timing protocol between RPIBOOSH and pylons).

## Done

- [x] OSC boosh trigger (`/pylon/BooshMain`)
- [x] HTTP REST API (solenoid on/off, telemetry, config)
- [x] Web UI with hold-to-fire button, live telemetry, config panel, log console
- [x] Status LEDs: IO12 white 1 Hz, IO13 yellow sine 1.2 Hz, IO14 blue sine 0.8 Hz, IO15 green sine 0.4 Hz
- [x] IO11 = HIGH when boosh active; IO38 = HIGH when Wi-Fi STA connected
- [x] Boosh failsafe (5-second forced OFF)
- [x] RPIBOOSH registry: announce + heartbeat with exponential backoff
- [x] Battery voltage sensing and % on IO3
- [x] Battery time-remaining estimation (rolling 20-min history)
- [x] Thermistor temperature on IO4 (Steinhart-Hart, calibrated)
- [x] Wi-Fi AP mode with captive portal (DNSServer, OS detection paths)
- [x] User-defined Wi-Fi fallback (SSID/password in NVS)
- [x] NVS config persistence (id, host, desc, ap_en, user WiFi)
- [x] Serial CLI for config
- [x] OLED 5-page display cycle
- [x] TWDT watchdog disabled for loopTask (prevents resets from blocking calls)
- [x] Web UI log scroll lock (only auto-scrolls when already at bottom)
- [x] Full documentation suite

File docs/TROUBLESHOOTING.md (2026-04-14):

# Troubleshooting

## Upload Fails / Port Not Found

- Use a data-capable USB-C cable (not charge-only).
- Check that the board appears in your device list.
- On normal boot, the firmware enumerates a USB CDC serial port automatically.
- If auto-reset fails, manually enter bootloader: hold `0`/BOOT, tap `RST`, release `0`, then start upload.
- After flashing, tap `RST` once to reboot. The COM port re-enumerates after a few seconds.
- If PlatformIO serial monitor was open, close it before uploading — it may hold the port.

## OLED Is Blank

- Confirm board is WEMOS/LOLIN S2 Pico (has built-in 128×32 SSD1306).
- I2C address must be `0x3C`.
- Reset pin must be `GPIO18`.
- Check `Wire.begin(8, 9)` is called before `display.begin()`.

## Serial Output Missing

- Confirm baud rate is `115200`.
- Ensure build flags `ARDUINO_USB_CDC_ON_BOOT=1` and `ARDUINO_USB_MODE=0` are set in `platformio.ini`.
- Watch for boot markers: `Boot: OLED ready`, `Boot: WiFi STA mode`, `WiFi scan...`.

## Wi-Fi Does Not Connect

- Verify SSIDs and passwords in `src/wifi_credentials.h`.
- ESP32-S2 supports 2.4 GHz only — 5 GHz networks are invisible.
- Each network attempt has a 15-second timeout before moving to the next.
- If all three networks fail, AP mode is auto-enabled.
- Connection order: Lava (`LL`) → dev (`MW`) → user-defined fallback.

## AP Mode Enabled Unexpectedly

If AP mode was auto-enabled because all STA networks failed, it is saved to NVS and persists on reboot. To disable:

```bash
# Via serial CLI
set ap false

# Via HTTP (when connected)
curl -X POST http://<pylon-ip>/api/config/ap -d "value=false"
```

Or use the web UI toggle.

## Cannot Connect to AP

- SSID is `PYLON_{id}` (e.g. `PYLON_PYLON5`) — open network, no password.
- Fixed IP is `10.1.2.3`.
- If captive portal does not appear, navigate directly to `http://10.1.2.3/`.

## OSC Not Responding

- Confirm UDP port `8000` is open on the network.
- OSC address is `/pylon/BooshMain` (not `/rpiboosh/BooshMain` — that was a legacy path).
- Message must have exactly one float argument: `1.0` (ON) or `0.0` (OFF).
- Test locally: press the `0`/BOOT button on the dev board (ON on press, OFF on release).

## Boosh Turns Off Unexpectedly

The 5-second failsafe forces OFF if no OFF message arrives within 5 s of ON. Serial log: `Failsafe: BooshMain timeout -> forcing OFF.`

This is intentional. Ensure the OFF message is sent promptly after ON.

## Battery / Temperature Reads Null

- Sensor values show `null` for the first poll cycle (~5 seconds after boot).
- If they remain null, check ADC wiring against [HARDWARE.md](HARDWARE.md).
- Battery ADC on IO3 reads 0 or 4095 if the divider is open or shorted — these are rejected.
- Thermistor ADC on IO4 reads 0 or 4095 if the NTC is open or shorted — these are also rejected.

## Battery Time Remaining Shows Null

Time remaining is estimated from a rolling 20-minute voltage history using 1-minute samples. It shows `null` until at least 5 samples are collected (~5 minutes after boot) and the battery is actively discharging.

## Registry Announce / Heartbeat Failing

- Check serial logs for `[REG]` prefixed lines.
- Confirm RPIBOOSH is reachable: `http://rpiboosh.local:5000`.
- If mDNS does not resolve `rpiboosh.local`, set `kRegistryBaseUrlFallback` to a fixed IP URL in `src/main.cpp`.
- Verify the registry service paths: `POST /api/pylons/announce`, `POST /api/pylons/heartbeat`.

## Device Resets After a Few Minutes (Watchdog)

Watchdog resets were caused by blocking HTTP and ping calls stalling the `loopTask` beyond the TWDT threshold. This is fixed in current firmware via `esp_task_wdt_delete(NULL)` in `setup()`, which removes `loopTask` from watchdog monitoring. If you see watchdog resets, confirm `#include "esp_task_wdt.h"` and the `esp_task_wdt_delete(NULL)` call are present in `src/main.cpp`.

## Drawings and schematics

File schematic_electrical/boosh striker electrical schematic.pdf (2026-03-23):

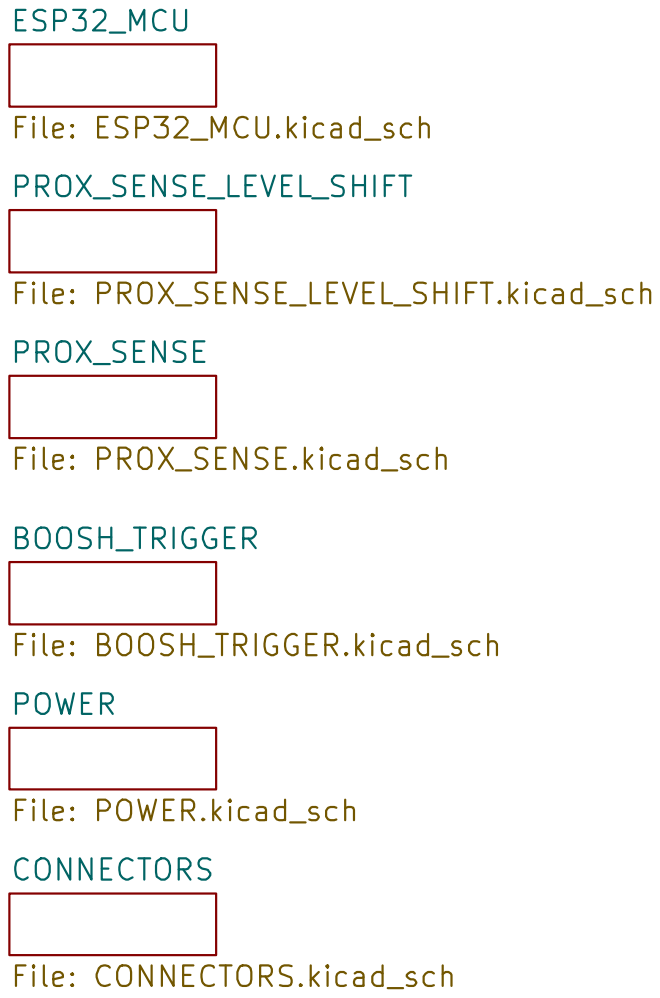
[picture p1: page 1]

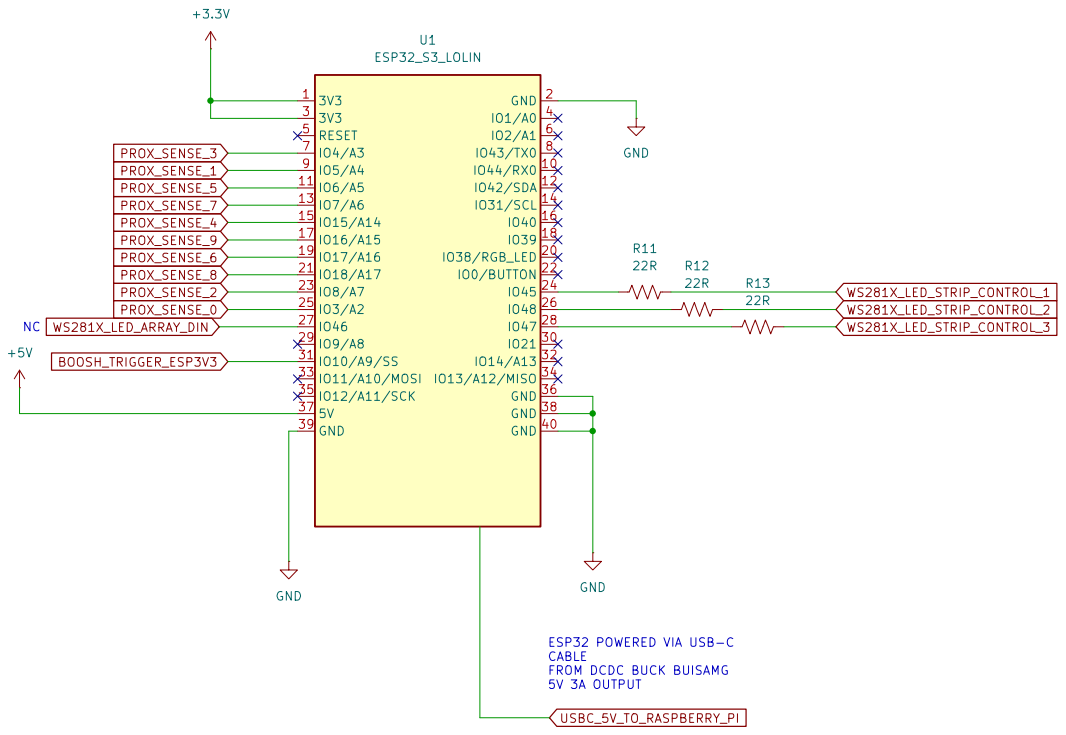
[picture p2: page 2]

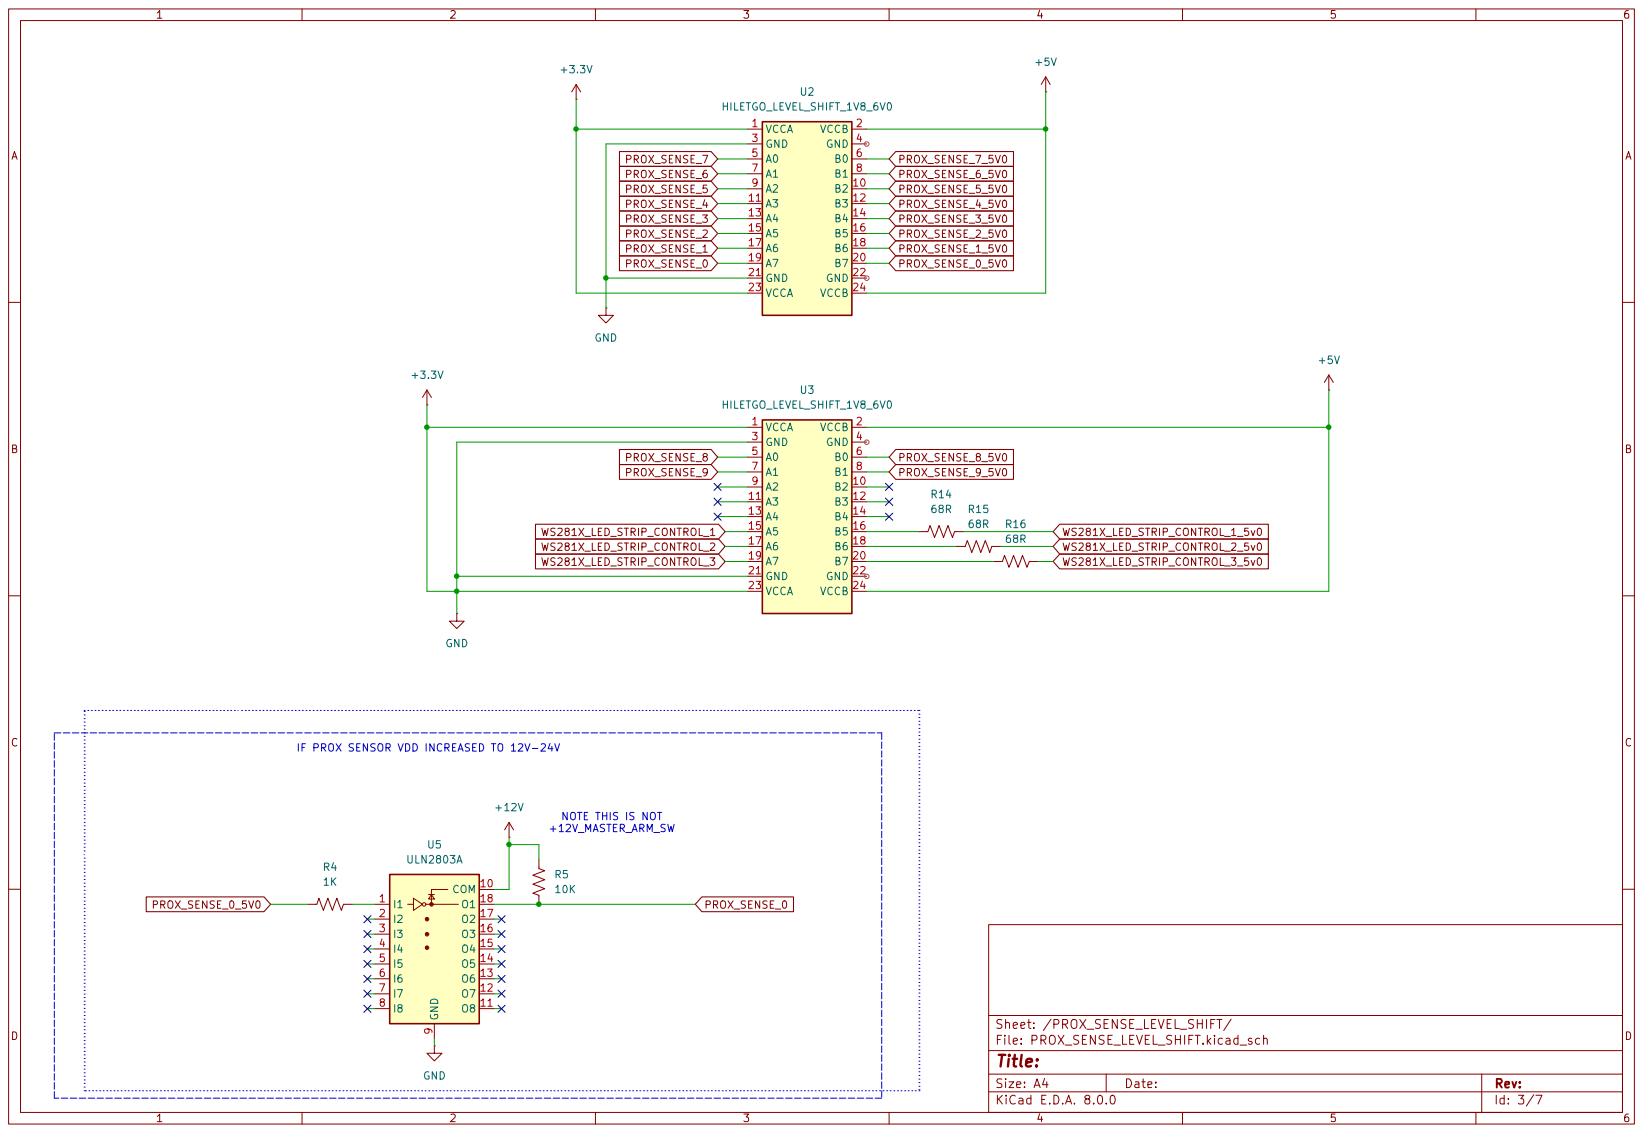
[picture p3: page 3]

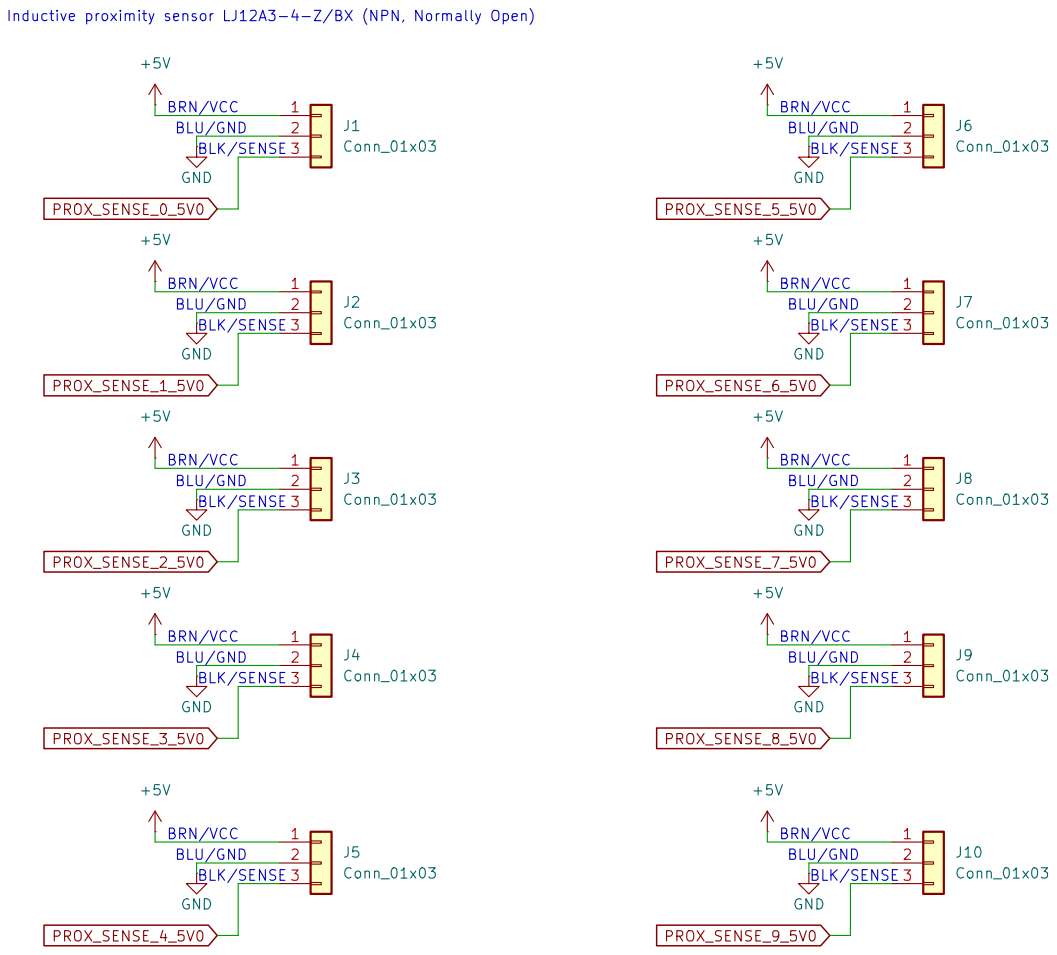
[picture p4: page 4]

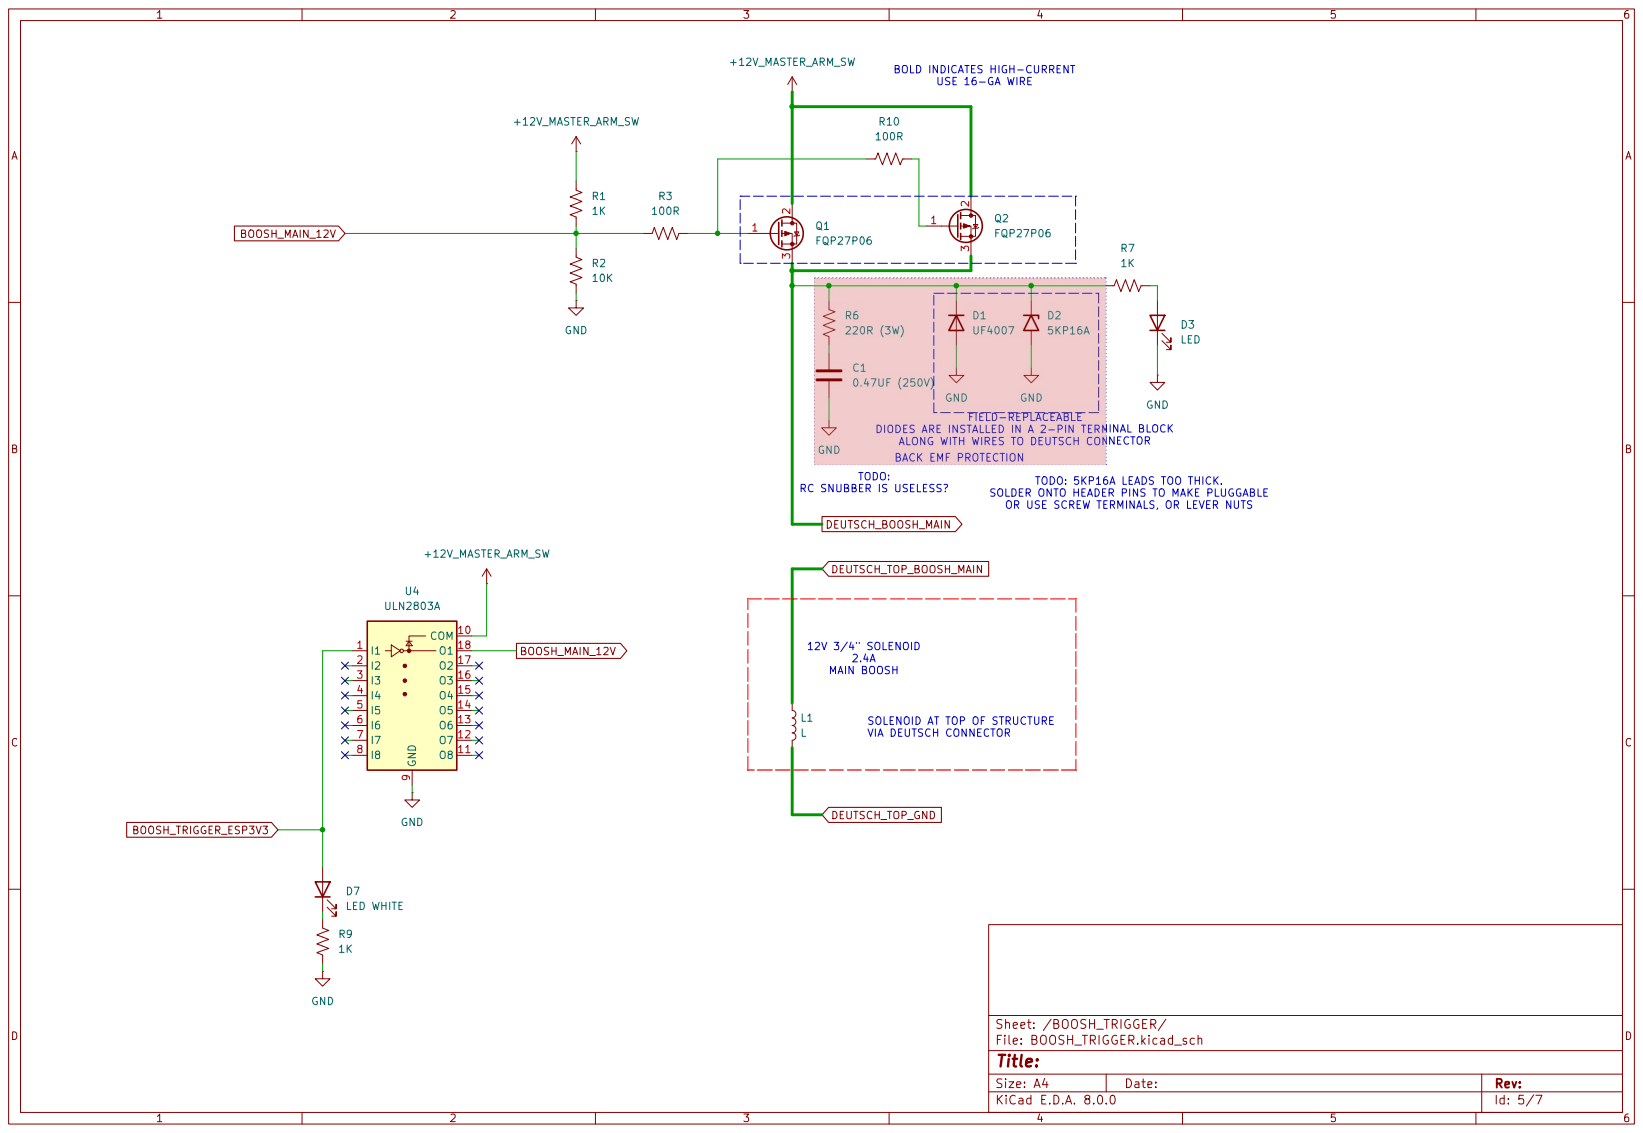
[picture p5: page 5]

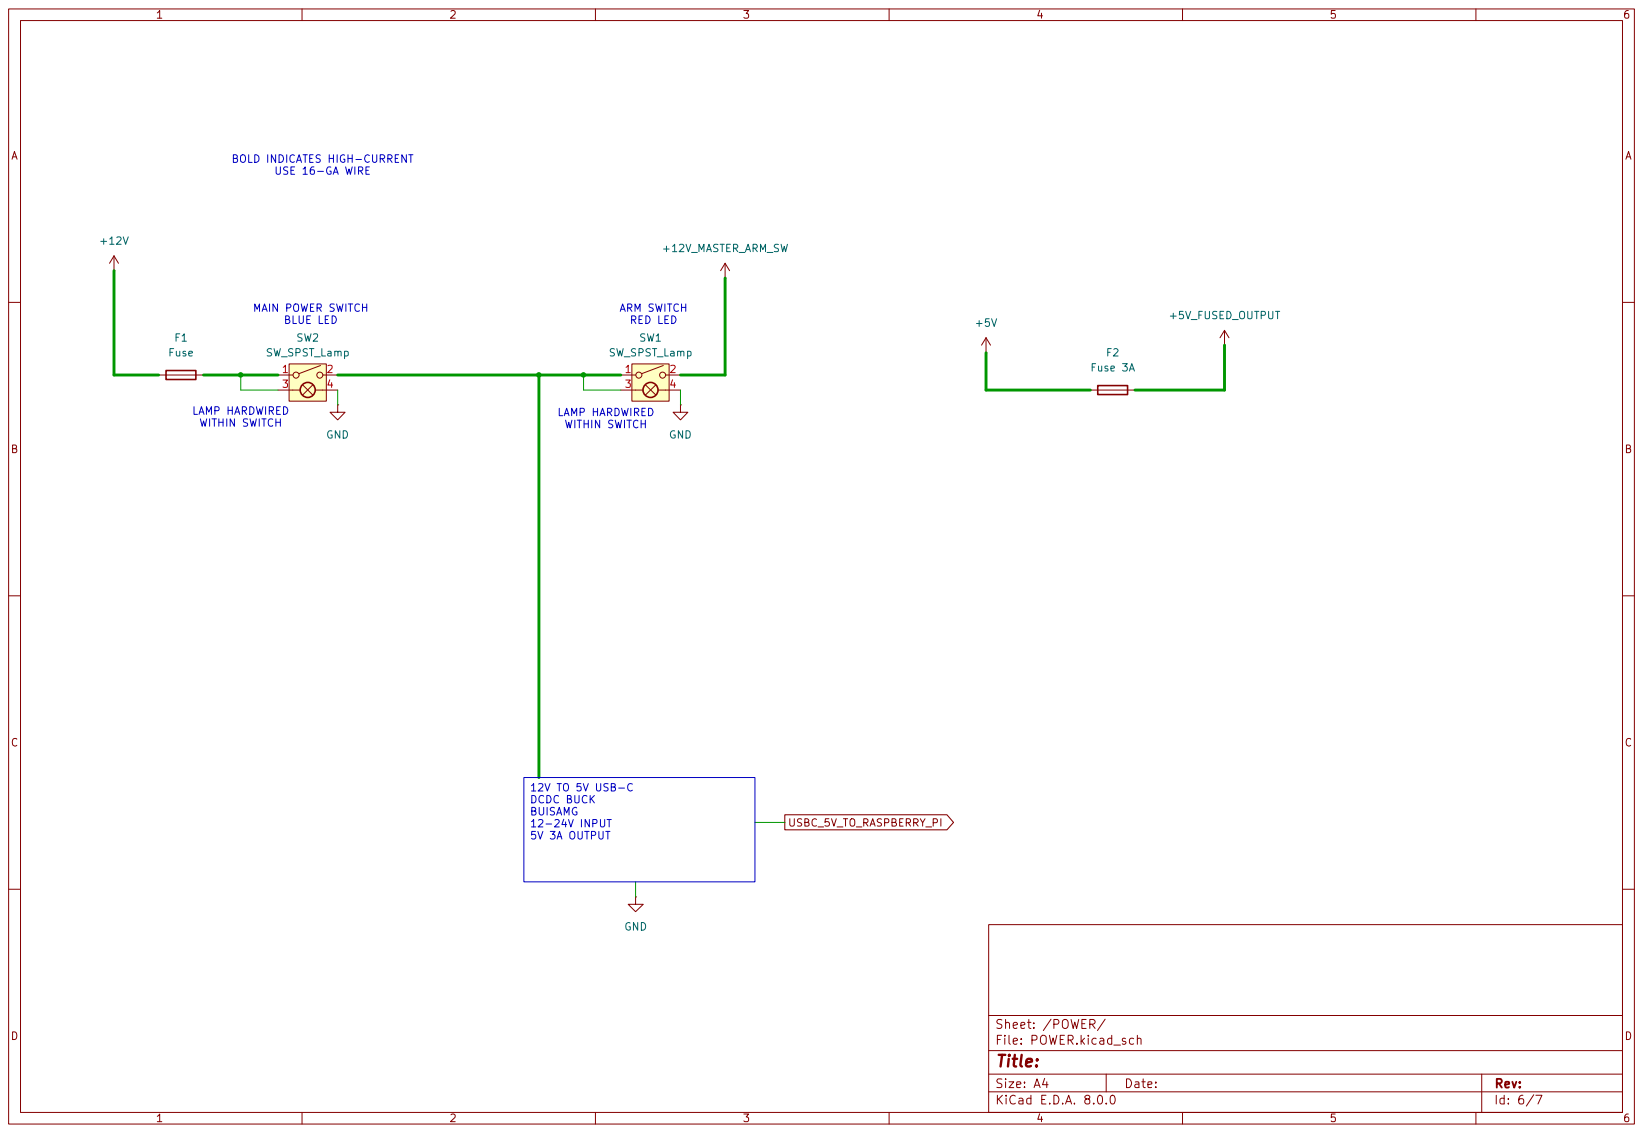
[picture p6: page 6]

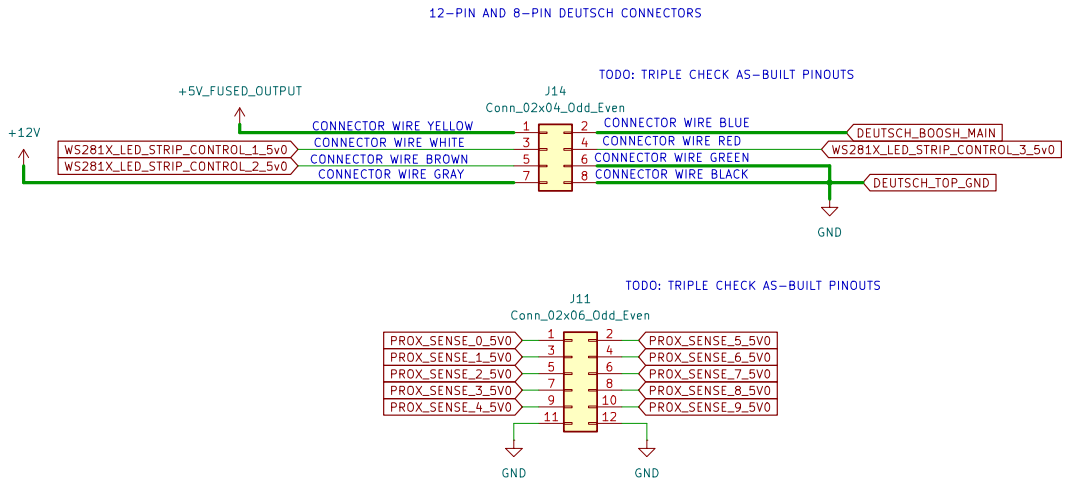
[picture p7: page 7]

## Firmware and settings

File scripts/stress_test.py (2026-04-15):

"""
stress_test.py  —  Pylon solenoid + telemetry stress test
==========================================================
Solenoid cycle  : every 6 s, hold open 4.5 s then off 1.5 s
Telemetry log   : every ~2 s, write all fields to CSV with PC timestamp
CSV flush       : every 60 s
Run             : python stress_test.py [host]
Stop            : Ctrl-C

Default host: http://testnodex.local
"""

import csv
import datetime
import sys
import threading
import time
import urllib.error
import urllib.request

# ---------------------------------------------------------------------------
# Config
# ---------------------------------------------------------------------------
HOST            = sys.argv[1] if len(sys.argv) > 1 else "http://testnodex.local"
SOLENOID_PERIOD = 6.0    # seconds between cycle starts
SOLENOID_ON     = 4.5    # seconds solenoid held open
TELEMETRY_PERIOD = 2.0   # seconds between telemetry samples
FLUSH_PERIOD    = 60.0   # seconds between CSV flushes
HTTP_TIMEOUT    = 5.0    # seconds for each HTTP call

# ---------------------------------------------------------------------------
# Helpers
# ---------------------------------------------------------------------------

def api(path, method="GET"):
    url = HOST.rstrip("/") + path
    req = urllib.request.Request(url, method=method)
    try:
        with urllib.request.urlopen(req, timeout=HTTP_TIMEOUT) as r:
            import json
            return json.loads(r.read().decode())
    except Exception as exc:
        print(f"  [HTTP {method} {path}] {exc}")
        return None


def flatten(data, prefix=""):
    """Recursively flatten nested dicts.  Lists become semicolon-joined strings."""
    out = {}
    for k, v in data.items():
        key = f"{prefix}{k}" if prefix else k
        if isinstance(v, dict):
            out.update(flatten(v, key + "."))
        elif isinstance(v, list):
            out[key] = ";".join(str(x) for x in v)
        else:
            out[key] = v
    return out


def csv_filename():
    ts = datetime.datetime.now().strftime("%Y%m%d_%H%M%S")
    return f"pylon_stress_{ts}.csv"


# ---------------------------------------------------------------------------
# Shared state
# ---------------------------------------------------------------------------
stop_event = threading.Event()

# ---------------------------------------------------------------------------
# Solenoid thread
# ---------------------------------------------------------------------------

def solenoid_thread():
    print(f"[solenoid] cycle: on {SOLENOID_ON}s / off {SOLENOID_PERIOD - SOLENOID_ON}s, period {SOLENOID_PERIOD}s")
    while not stop_event.is_set():
        cycle_start = time.monotonic()

        resp = api("/api/solenoid/on", method="POST")
        if resp:
            print(f"  [solenoid] ON  -> {resp.get('solenoid_active')}")

        # Wait SOLENOID_ON seconds (interruptible)
        stop_event.wait(SOLENOID_ON)
        if stop_event.is_set():
            break

        resp = api("/api/solenoid/off", method="POST")
        if resp:
            print(f"  [solenoid] OFF -> {resp.get('solenoid_active')}")

        # Sleep remainder of the period
        elapsed = time.monotonic() - cycle_start
        remaining = SOLENOID_PERIOD - elapsed
        if remaining > 0:
            stop_event.wait(remaining)


# ---------------------------------------------------------------------------
# Telemetry / CSV thread
# ---------------------------------------------------------------------------

def telemetry_thread():
    filename = csv_filename()
    print(f"[telemetry] logging to {filename}")

    csvfile = open(filename, "w", newline="", buffering=1)
    writer = None
    fieldnames = None
    last_flush = time.monotonic()
    sample_count = 0

    try:
        while not stop_event.is_set():
            loop_start = time.monotonic()

            data = api("/api/telemetry")
            if data is not None:
                row = {"_timestamp": datetime.datetime.now().isoformat(timespec="milliseconds")}
                row.update(flatten(data))

                if writer is None:
                    fieldnames = list(row.keys())
                    writer = csv.DictWriter(csvfile, fieldnames=fieldnames, extrasaction="ignore")
                    writer.writeheader()
                else:
                    # Add any new keys that weren't in the first row
                    for key in row:
                        if key not in fieldnames:
                            fieldnames.append(key)

                writer.writerow(row)
                sample_count += 1
                batt = row.get("battery_voltage_v", row.get("telemetry.battery_voltage_v", "?"))
                temp = row.get("temperature_f",     row.get("telemetry.temperature_f",     "?"))
                ping = row.get("telemetry.ping.last_ms", "?")
                sol  = row.get("solenoid_active", "?")
                print(f"  [telemetry #{sample_count}] batt={batt}V  temp={temp}°F  ping={ping}ms  solenoid={sol}")

            # Flush CSV every FLUSH_PERIOD seconds
            if time.monotonic() - last_flush >= FLUSH_PERIOD:
                csvfile.flush()
                last_flush = time.monotonic()
                print(f"  [csv] flushed ({sample_count} rows so far)")

            # Sleep the remainder of the 2-second interval
            elapsed = time.monotonic() - loop_start
            remaining = TELEMETRY_PERIOD - elapsed
            if remaining > 0:
                stop_event.wait(remaining)

    finally:
        csvfile.flush()
        csvfile.close()
        print(f"[telemetry] closed {filename}  ({sample_count} rows total)")


# ---------------------------------------------------------------------------
# Main
# ---------------------------------------------------------------------------

def main():
    print(f"Pylon stress test  ->  {HOST}")
    print(f"  Solenoid: on {SOLENOID_ON}s every {SOLENOID_PERIOD}s")
    print(f"  Telemetry: every {TELEMETRY_PERIOD}s  |  CSV flush every {FLUSH_PERIOD}s")
    print("  Ctrl-C to stop\n")

    # Confirm connectivity
    info = api("/api/telemetry")
    if info is None:
        print(f"ERROR: cannot reach {HOST}  — check host and Wi-Fi")
        sys.exit(1)
    print(f"  Connected: {info.get('pylon_id','?')}  FW {info.get('fw_version','?')}\n")

    t_solenoid  = threading.Thread(target=solenoid_thread,  daemon=True, name="solenoid")
    t_telemetry = threading.Thread(target=telemetry_thread, daemon=True, name="telemetry")

    t_solenoid.start()
    t_telemetry.start()

    try:
        while t_solenoid.is_alive() or t_telemetry.is_alive():
            time.sleep(0.25)
    except KeyboardInterrupt:
        print("\nStopping…")
        stop_event.set()
        # Make sure solenoid ends up off
        api("/api/solenoid/off", method="POST")
        t_solenoid.join(timeout=3)
        t_telemetry.join(timeout=5)
        print("Done.")


if __name__ == "__main__":
    main()

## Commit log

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2026-03-23 feat(registry): announce/heartbeat ESP32 PYLON to RPIBOOSH API
    - add HTTP registry client in src/main.cpp
    - announce on Wi-Fi connect/reconnect via /api/pylons/announce
    - heartbeat every 10s via /api/pylons/heartbeat
    - include metadata payload: pylon_id, description, hostname, ip, osc_port, osc_paths, roles, fw_version, ttl_sec
    - add exponential backoff (cap 30s) and short HTTP timeouts
    - make mDNS host configurable via kPylonMdnsHost (default PYLON0)
    - preserve existing OSC /rpiboosh/BooshMain behavior and failsafe logic
    - document integration and troubleshooting
2026-03-23 feat(device-config): persist PYLON identity, add serial CLI, and OLED node diagnostics
    - replace fixed id/host/description constants with NVS-backed runtime config
    - default unprogrammed config to PYLON + STA MAC LSB bytes and desc=unspecified
    - add CLI commands: help/show/set id/set host/set desc/set node/clear nvs
    - persist updates, refresh mDNS hostname, and trigger registry re-announce
    - accept CR or LF for CLI line endings (PuTTY-friendly)
    - add OLED NODE CONFIG page showing current id/description
    - add PuTTY session import profile for COM16 monitoring
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2026-04-13 Pylon schmatic: clarify filenames and add orange text to avoid confusing other similar schematic pages.
    [BOOSH_TRIGGER.kicad_sch, CONNECTORS.kicad_sch, ESP32_MCU.kicad_sch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]
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2026-04-14 Complete documentation suite and fix stale OSC path references
    - Add docs/API.md: full HTTP REST and OSC reference
    - Add docs/CONFIG.md: NVS, serial CLI, and HTTP config API reference
    - Add docs/HARDWARE.md: GPIO pinout, battery/thermistor circuits, PWM mapping
    - Add docs/IDEA.md: speculative feature backlog
    - Add docs/TODO.md: open/done task tracking
    - Rewrite docs/README.md: architecture, boot sequence, main loop, all features
    - Rewrite docs/SETUP.md: dependencies, upload, credential file setup
    - Rewrite docs/WIFI.md: connection priority, AP mode, captive portal
    - Rewrite docs/DISPLAY.md: OLED page layout with current 5-page cycle
    - Rewrite docs/PYLON_REGISTRY.md: payload contract with liv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
2026-04-15 Calibrate ADC for ESP32-S2 Vref error (battery + thermistor)
    ESP32-S2 ADC effective Vref is ~2.9V not 3.3V, causing raw counts to
    read ~23% high. Derived correction factor 0.810 from measured battery
    data (actual vs. reported at 10-14V range, mean ratio 1.234).
    - Add kAdcCalFactor = 0.810f
    - ReadBatteryVoltage: multiply output by kAdcCalFactor
    - ReadThermistorF: divide raw by kAdcCalFactor before resistance calc
    (nonlinear formula requires correction at raw level, not output)
    - Document calibration data and derivation in HARDWARE.md
    Temperature will read ~91F at the measured 1.737V ADC input (was 113F).
    Fine-tune kThermistorOffsetF once a calibrated reference is available.
    Co-Authored-B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
2026-04-15 2-point linear temperature calibration
    Replace single-offset Steinhart-Hart correction with a proper linear
    calibration derived from two measured reference points:
    actual 37.9°F @ reported 46.5°F
    actual 156.9°F @ reported 126.81°F
    → slope 1.482, intercept -31.0°F on firmware output
    → kThermistorCalScale=1.482, kThermistorCalOffsetF=-14.46 on raw S-H output
    Removes kThermistorOffsetF (folded into the new constants).
2026-04-15 Recalibrate thermistor, add reset reason to web UI, increase LED brightness
    - Thermistor 2-point calibration redone with equilibrated reference points
    (48.3°F and 116°F); prior calibration used a non-equilibrated 156.9°F point
    that produced a bad slope. New: scale=0.9116, offset=+13.92°F
    - Add last_reset_reason to telemetry API and web UI (esp_reset_reason())
    - Increase PWM LED brightness from 33% to 66% duty cycle
    - Schematic: update R8 value label to 22k (as built), clean CONNECTORS page
    [CONNECTORS.kicad_sch, ESP32_MCU.kicad_sch]
2026-04-15 Add HTTP OTA firmware update with web UI
    POST /api/ota accepts a multipart firmware.bin upload, writes it to the
    inactive OTA partition via the Update library, and reboots on success.
    Web UI adds a Firmware Update panel with file picker, progress bar, and
    status feedback. Partition table already has two OTA slots; no changes
    to platformio.ini needed.
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2026-04-15 Add battery voltage history charts to web UI
    Two server-side SVG chart endpoints served from ESP32 RAM ring buffers:
    - /api/chart/battery/short: 30 min at 10 s/sample (180 points, 1.4 KB)
    - /api/chart/battery/long: 24 h at 1 min/sample (1440 points, 11.5 KB)
    Charts auto-refresh every 15 s in the browser via cache-busting img src.
    SVG rendered server-side (no JS charting library): polyline trace, Y grid
    at 10-15 V, time-ago X labels, current voltage label at right edge.
    RAM increase: 17% -> 21% (12.7 KB for buffers).
    Sampling piggybacks on existing PollSensors() battery read.
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2026-04-15 Add checkerboard OLED animation to identify mode
    During identify mode, ShowIdentifyScreen() renders an 8x8 checkerboard
    XOR overlay on top of an 'IDENTIFY' label, flipping phase every 200 ms
    (5 Hz crawl). Runs in parallel with the LED blink for the full 10 s.
    Normal display page cycle resumes immediately after identify expires.
2026-04-16 Add temperature history charts; generalize chart SVG builder
    - Two new chart panels: Temperature 30 min and 24 h (auto-scaled Y axis)
    - BuildBatterySvg replaced by general BuildChartSvg:
    - Accepts y_min/y_max (NAN = auto-scale from data with 12% padding)
    - NiceStep() picks human-friendly Y grid intervals (1/2/5/10...)
    - Configurable stroke color and value label format
    - Battery charts now call BuildChartSvg with fixed 10-15 V range
    - Temperature charts use green (#7ce3b0) and auto-scale
    - RAM: 21% -> 25% (12.7 KB for two new 1440+180-point ring buffers)
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2026-04-16 Switch ADC to analogReadMilliVolts(); recalibrate thermistor
    Replace empirical kAdcCalFactor (0.810) with analogReadMilliVolts() which
    uses the per-chip eFuse factory calibration. Battery voltage verified <0.8%
    error across 8-14V with no software trim needed.
    Thermistor cal rederived on TIKI1 with the new ADC path:
    scale=0.9775, offset=+0.20°F (2-point: 36°F and 73°F reference).
    Previous cal constants (scale=0.9116, offset=+13.92°F) were derived against
    the old kAdcCalFactor-corrected raw counts and are no longer valid.
    Update HARDWARE.md with verified calibration tables and new formulas.
2026-04-16 Add expansion buttons/lamps schematic sheet; schematic cleanup and annotations
    - New EXPANSION_BUTTONS_LAMPS.kicad_sch sheet wired into top-level schematic
    - Add AB_800T-QT24 symbol library
    - ESP32_MCU: wire previously unconnected GPIO pins to BUTTON0-4 and BUTTON_LAMP_PWM_OUT0-4 global labels; add expansion IO bounding box annotation
    - POWER: add GND ganging fabrication notes, DCDC USB wiring note, fuse value updated to "10A MINI AUTO BLADE"; routing cleanup
    - CONNECTORS: routing and junction cleanup
    - BOOSH_TRIGGER: remove stale "1R" errata note
    - IDEA.md: add sandbox notes and open questions
    [BOOSH_TRIGGER.kicad_sch, CONNECTORS.kicad_sch, ESP32_MCU.kicad_sch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]
2026-04-16 Split OLED stats into two larger-font views
    View 1 (50%): temp + voltage — size-3 digits (18×24px, fills screen height)
    with size-1 units subscripted at y=24. Gap auto-computed from remaining width.
    View 2 (25%): battery time remaining + pct — size-2 digits, size-1 units
    bottom-aligned. Shows "--" for missing/negative time remaining.
    Other views (25%): ping/wifi/wifi-detail/node/firmware cycled evenly.
2026-04-16 Improved battery estimator; redesigned OLED display views
    Estimator:
    - Sample interval 1 min → 5 min; buffer 20 pts → 72 pts (6 h of history)
    - Oldest-vs-newest slope → linear regression over all points (much more
    stable on flat LiFePO4 discharge curve)
    - Min required samples 5 → 12 (~1 hour before first estimate)
    - Discharge threshold lowered from 1e-7 to 5e-7 V/s to catch slow
    multi-day discharge rates
    - Clamp output to [0, 500 h]; negative values stored as -1 (shown as --)
    OLED views:
    - View 1 (50%): temp °F + battery % — size-3 digits, size-1 units subscript
    Disconnected probe (outside -40..200°F) shows "-" instead of garbage
    - View 2 (25%): time remaining H:MM + volta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
2026-04-17 Parameterize solenoid failsafe timeout via NVS and web UI
    - New NVS key failsafe_ms (uint32), default 5000 ms, valid range 1-60 s
    - boosh_failsafe_timeout_ms runtime variable replaces kBooshFailsafeTimeoutMs
    in the main loop check
    - LoadPylonConfig / SavePylonConfig persist the value
    - SetConfigFieldValue handles 'failsafe_s' (seconds, float) and 'failsafe_ms'
    with range validation; CLI: set failsafe_s <value>
    - HandleConfigPostApi accepts failsafe_s argument
    - BuildConfigApiJson and BuildTelemetryApiJson both expose failsafe_ms
    (telemetry needed so web UI stays in sync after every refresh)
    - PrintPylonConfig shows current value
    - Web UI: numeric input (1-60 s, 0.1 step) in Node Config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
2026-04-17 Swap blue/yellow LED pin assignments to match as-built hardware
    IO13=blue, IO14=yellow (reversed from original schematic).
    Updated schematic reflects actual board assembly.
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2026-04-17 BARMODE btn0: boosh-all OSC on press/release; chase LEDs; OLED invert
    Button 0 in barmode now sends /pylon/BooshMain 1.0 to all registry pylons
    on press and 0.0 on release. While held: blue→yellow→green 100ms chase
    overwrites all 3 LEDs, and the OLED display inverts. The existing yellow/
    green blink-seq still runs alongside.
    Also triggers immediate registry fetch at barmode boot (no 10-second dead
    zone before first pylon list is available).
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2026-04-21 v0.0.3: barmode OLED 180deg, skip sensor pages, button lamp patterns (green sine/blue pulse/red LAVA morse+steam/orange sawtooth)
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2026-04-21 Green btn timed pulse (300ms), all-4 hold escalating strobe+valve, blue lamp 50ms
    Green button (btn0) no longer holds valve open while pressed; fires a timed
    pulse of barmode_green_timeout_ms (default 300ms, NVS-persisted, web UI input).
    Blue lamp pulse shortened back to 50ms. All-4-buttons simultaneous hold triggers
    escalating lamp strobe (25%@2Hz → 50%@4Hz → 75%@6Hz → 80%@8Hz) and opens all
    pylon valves at 3s hold; valves close on release or after 3 further seconds.
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2026-04-21 Sequential 4-button unlock (blue 3s→green 3s→orange 2s→red 2s), button ref panel
    Replace simultaneous all-4 hold with a deliberate 4-step unlock sequence:
    hold blue 3s, then add green 3s, then add orange 2s, then add red 2s to open
    all valves. Each phase has distinct lamp feedback (25/50/75/80% strobe).
    Releasing any anchor button resets the sequence. Adds a Button Reference
    panel to the web UI (barmode only) documenting all single-button actions and
    the full unlock sequence with lamp/timing details.
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2026-04-21 Schematic as built for bar box. 12V fire enable switch wired in correct manner such that LED is off when switch is off.
    [BOOSH_TRIGGER.kicad_sch, EXPANSION_BUTTONS_LAMPS.kicad_sch, POWER.kicad_sch]
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2026-04-21 IP fallback for all HTTP calls (registry GET, BPM fetch)
    Barmode registry GET now falls back to target_ip_string when rpiboosh.local
    mDNS resolution fails (-1). BPM fetch resolves llled.local once, caches IP,
    falls back to IP on mDNS failure. Fixes repeated registry fetch failed: -1
    log spam on nodes where ESP32 mDNS resolution is unreliable.
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2026-04-21 Configurable OSC actions, formDirty fix, steam units ms, registry Idx column, red seq mode
    - OSC actions (pulse-once, pulse-train, steam) now have configurable durations/counts
    and per-action disable toggles; all NVS-persisted; shown in web UI for all pylons
    - Pylon index exposed in All Buttons section (not just barmode)
    - Registry table shows Idx column per pylon
    - formDirty flag prevents telemetry refresh from reverting user-typed config values
    - Steam ramp/open units changed from seconds to milliseconds
    - Timing inputs use step="1" to allow arbitrary ms values (e.g. 66ms valve open)
    - Red button sequential mode: ping-pong OSC fire across registry pylons
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2026-04-21 Recovery: temp multipliers + formDirty fix for recovery inputs + step=1
    - Two temperature thresholds (°F) each with a multiplier; if avg pylon
    temp drops below a threshold, all recovery periods are scaled by that
    multiplier. If both thresholds are breached, only the colder one applies.
    - Barmode polls each pylon /api/telemetry every 2 min (PingTask/Core 0)
    to compute avg temp; ignores readings <= -40F (disconnected sensor)
    - ApplyTempMult() applied at recovery-start time for all 4 buttons
    - Web UI shows threshold/multiplier inputs, avg temp, active multiplier,
    and effective recovery per button when multiplier is > 1
    - Fixed recovery inputs: step=1 (was 500, causing browser quantizat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
2026-04-21 Fix formDirty revert bug (third time — now systematic + documented)
    Root causes eliminated:
    1. configInputs array was missing all recently-added inputs (recovery,
    temp threshold, red seq, OSC action params). Only 'input' events were
    caught via form-level listener; 'change' (spinners, paste, autofill)
    was silently missed, leaving formDirty=false and allowing overwrites.
    2. Direct activeElement pattern used instead of syncConfigField — bypasses
    the formDirty guard when focus moves to Save button mid-type.
    Fix:
    - configInputs now lists every synced input in the config form
    - All telemetry sync calls use syncConfigField() exclusively
    - Display-only spans moved outside the formDi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
2026-04-26 BARMODE all-4: rpiboosh solenoid API + OSC proxy routing
    All-4 sequence now opens main+ring solenoids on rpiboosh via
    POST /api/solenoid/main|ring/open|close, with 3s keepalive to
    reset the server-side 5s auto-close timer. Runs on Core 0 (PingTask)
    so HTTP never blocks the main OSC loop.
    Add cfg_route_via_rpi setting (NVS-persisted, web UI checkbox in
    barmode Network Routing section): when enabled, SendOscFloatToIP
    enqueues messages to a FreeRTOS queue instead of sending UDP directly;
    PingTask drains queue and forwards each via POST /api/osc/send on
    rpiboosh using target pylon cached IP as host field.
2026-05-04 Mesh: fix ESP-NOW channel — use peer.channel=0 in STA mode
    In STA mode the WiFi channel is locked by the AP; calling
    esp_wifi_set_channel() silently fails and peer.channel=N causes
    ESP-NOW to attempt transmission on the wrong channel. Nobody
    receives beacons → peer_count stays 0.
    Fix: remove esp_wifi_set_channel() call, set peer.channel=0
    (follow current WiFi channel) and ifidx=WIFI_IF_STA. Also fix
    recv callback to check len>=6 before reading data[5] (pkt_type).
    Tested: all 3 nodes (barbar, testredled, pylon5d90) immediately
    see 2 peers each on first beacon cycle after reboot.
2026-05-04 Mesh: POST /api/mesh/relay + web UI relay panel + larger OLED badge
    API: POST /api/mesh/relay (addr=<osc_addr>&arg=<float>)
    Lets any non-ESP-NOW node (rpiboosh, curl) relay an OSC command
    onto the mesh via MeshBroadcastOsc. Returns {ok, addr, arg, peers}.
    Returns 503 if mesh not active, 400 if addr missing.
    Web UI: "Relay OSC via Mesh" sub-panel inside the MESH section.
    Shows OSC addr + arg inputs and a Send button; displays result
    (peer count or error). Also shows the API curl format for reference.
    OLED: DrawMeshBadge() now accepts text_size param (default=2).
    RenderDisplayPage (ping/wifi/node/firmware pages) uses size-2 badge
    at top-right (12px/char, 16px tall — much more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
2026-05-04 Failsafe: arm during sequences (PULSE_ONCE, PULSE_5X, STEAM)
    SeqSetSolenoid previously disarmed the failsafe unconditionally,
    leaving the valve unprotected during sequence open phases if the
    main loop ever stalled. Now SeqSetSolenoid(true) arms the failsafe
    (same timeout as BooshMain), SeqSetSolenoid(false) disarms it.
    The failsafe fires at boosh_failsafe_timeout_ms regardless of how
    the valve was opened. PollSequence() still closes on schedule
    normally; the failsafe is just a backup if the loop stalls.
2026-05-04 Mesh: fix double-send in button handlers; OLED badge on all pages
    Remove redundant MeshBroadcastOsc calls from PollBarModeButtons — all
    button handlers already reach mesh peers via SendOscFloatToAllPylons
    (which calls MeshUnicastOsc per peer). The duplicate broadcast caused
    StartSequence to fire twice on mesh peers, restarting sequences mid-
    execution and defeating the failsafe by reopening a closing valve.
    MeshBroadcastOsc is now used only in relay paths: HandleOscMessage
    (incoming UDP relay to mesh) and HandleMeshRelayApi (/api/mesh/relay).
    Also add DrawMeshBadge(0, 2) to ShowTempPctPage and standardise
    ShowTimeVoltagePage from size-1/y=24 to size-2/y=0, matching the
    badge size and pos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
2026-05-05 Mesh: pin WiFi channel on AP disconnect to stabilise ESP-NOW
    When the AP drops, WiFi.setAutoReconnect causes the radio to scan
    channels, making peer.channel=0 point at a moving target. Open
    commands get through intermittently but close commands can be lost
    entirely, leaving valves open and relying solely on the failsafe.
    Fix: on ARDUINO_EVENT_WIFI_STA_DISCONNECTED, call
    esp_wifi_set_channel(cfg_mesh_ch) to pin the radio while disconnected
    (valid per ESP-IDF docs when STA is disassociated). Re-pin after each
    manual reconnect attempt in case the scan moved it. AP re-association
    automatically reasserts the correct channel on reconnect.
2026-05-05 Mesh: continuously re-pin WiFi channel while AP is offline
    A one-time channel pin at disconnect is insufficient: setAutoReconnect
    and manual WiFi.reconnect() trigger asynchronous background scans that
    un-pin the channel after the call returns. Fix: re-assert cfg_mesh_ch
    every 3 s inside the disconnect block of loop() so any scan-induced
    drift is corrected within one tick. Removes the now-redundant one-shot
    re-pin from the reconnect watchdog.
2026-05-05 Mesh: fix channel stability — event-pin + disable auto-reconnect
    The 3s loop re-pin caused self-induced disruption (esp_wifi_set_channel
    interrupts the radio even when already on the target channel). Revert
    to event-driven pin: ARDUINO_EVENT_WIFI_STA_DISCONNECTED fires on every
    failed reconnect attempt, so the pin is automatically re-asserted each
    time without polling.
    Disable WiFi.setAutoReconnect when mesh is enabled — background reconnect
    scans change the channel asynchronously and were un-pinning us between
    manual reconnect windows. The manual watchdog in loop() (3 min) handles
    WiFi recovery when the AP comes back.
2026-05-05 BarMode: self-trigger local solenoid + web virtual buttons + reconnect fix
    Self-trigger: all button actions (green BooshMain, blue PulseSingle, orange
    PulseTrain, red steam, ALL-4 sequence open/close) now also fire the barmode
    node's own solenoid/sequences alongside the remote OSC fanout. Sequence
    disable flags (action_pulse1_dis etc.) are respected for local firing.
    Virtual buttons: web UI gains 4 round buttons (green/blue/orange/red) in
    a new Virtual Buttons panel (barmode-only). Buttons animate with the same
    idle blink patterns as the physical lamps (BPM-synced sine/sawtooth/strobe
    via requestAnimationFrame). Pressing a web button POSTs to /api/barmode/btn
    which sets web_btn_pressed[]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
2026-05-05 BarMode: red seq self-trigger + solenoid panel relayout
    - PylonTarget gains is_self flag; SendOscToPylonTarget calls
    ApplyBooshState directly when is_self=true, no OSC send
    - Red sequential now appends BARBAR as one ping-pong slot
    (cap ExtractRegistryTargets at 15 to keep room for self)
    - Fix compile error: barmode_red_state_g mirror moved inside
    red button block where red_state is in scope
    - Move solenoid/sequence control buttons (Press and Hold,
    Blink LEDs, Pulse once/5x, Steam engine) into their own
    panel section below Virtual Buttons panel
2026-05-05 BarMode web UI: virtual buttons fullscreen mode on mobile
    On mobile (<=640px), virtual buttons panel defaults to fullscreen
    (covers full viewport) so all 4 buttons get maximum touch area.
    A toggle button (top-right of panel) switches between fullscreen
    and the existing fixed-bottom strip. Choice is persisted in
    localStorage. First activation defaults to fullscreen on mobile,
    inline on desktop.
2026-05-05 Fix: PylonTarget.is_self uninitialized — remote nodes not getting OSC
    ExtractRegistryTargets never set is_self=false for normal targets.
    Stack-allocated PylonTarget arrays had garbage in that byte, causing
    SendOscToPylonTarget to call ApplyBooshState locally instead of
    sending OSC/mesh, silently dropping commands to remote nodes.
    Fix: explicitly set is_self=false in all three target-fill paths.
    Also: /api/mesh/relay now applies the OSC command locally in addition
    to broadcasting via ESP-NOW, so BARBAR fires alongside mesh peers.
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2026-05-05 Fix: null barmode_registry_mutex causes infinite hang on non-barmode nodes
    ExtractRegistryTargets and ExtractRegistryIPs called xSemaphoreTake()
    on barmode_registry_mutex without a null check. On non-barmode PYLONs
    the mutex is never initialized (stays nullptr). xSemaphoreTake(nullptr)
    triggers FreeRTOS configASSERT which spins forever with interrupts
    disabled — display freezes, WiFi stack dead, no WDT recovery.
    Trigger: HandleDjBtn (and the DJ timeout watchdog) called
    SendOscFloatToAllPylons unconditionally. Any non-barmode PYLON with
    the DJ page open and button pressed would hang permanently.
    - ExtractRegistryTargets/IPs: return 0 early if mutex is null
    - HandleDjBtn + DJ watchdog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
2026-05-05 Docs + fixes: mesh protocol doc, formDirty banner, chan change, fw_ver[32]
    - CLAUDE.md: add full ESP-NOW mesh protocol section (constants, structs,
    channel management rules, dedup, beacon spec); update formDirty rule to
    explicitly cover <select> elements (regressed 5th time on mesh-ch-sel)
    - formDirty: add hard-to-miss banner comment above configInputs array
    - mesh-ch-sel: add to configInputs, sync via syncConfigField (bug fix)
    - fw_ver[16] -> fw_ver[32] in MeshBeaconPkt + MeshPeerInfo; kMeshVersion 2->3
    - kMeshPktChanChange (type=3): broadcast coordinated channel switch with 5s
    countdown; MeshBroadcastChanChange; HandleMeshChanChangeApi; web UI dropdown
    - Red sequential: RedSeqClose[1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
2026-05-06 Fix: WiFi stability — idempotent MeshInit, AP channel anchor on STA disconnect
    - MeshInit() is now safe to call multiple times: FreeRTOS mutex/queue are
    created once and reused; ESP-NOW is properly deinit'd before re-init.
    Previous code called esp_now_init() twice on boot whenever ap_enabled=true
    was saved in NVS (SetupApMode+MeshInit→setup+MeshInit), causing silent
    failure or crash.
    - SetupApMode/StopApMode: guard MeshInit() call with mesh_initialized so
    re-init only fires on runtime mode changes, not at initial boot.
    - On STA disconnect while AP is active (e.g. after channel-mismatch force-
    disconnect from basketballshorts), main loop restarts the softAP on
    cfg_mesh_ch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
